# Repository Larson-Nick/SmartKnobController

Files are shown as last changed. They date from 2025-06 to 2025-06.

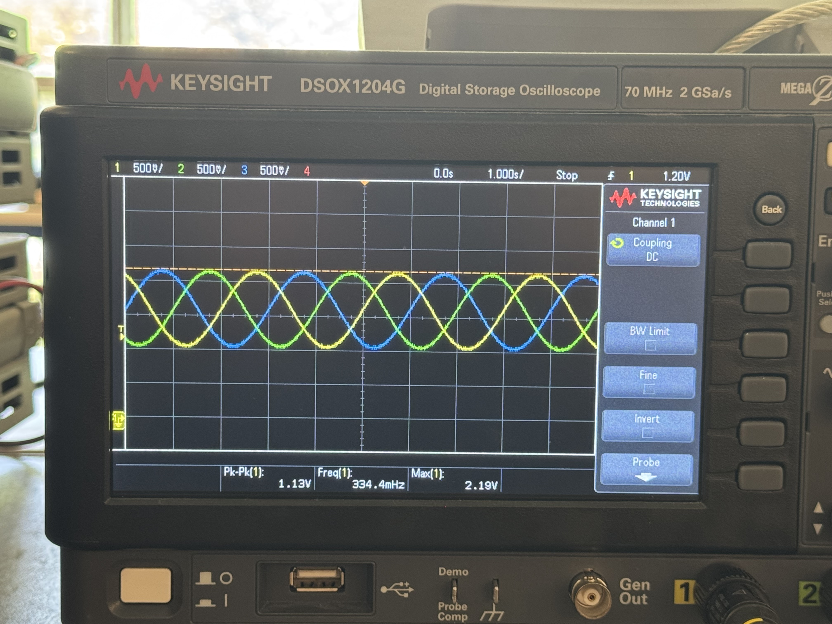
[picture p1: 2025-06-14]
Hardware/MEDIA/SinusoidalCommutation.jpg

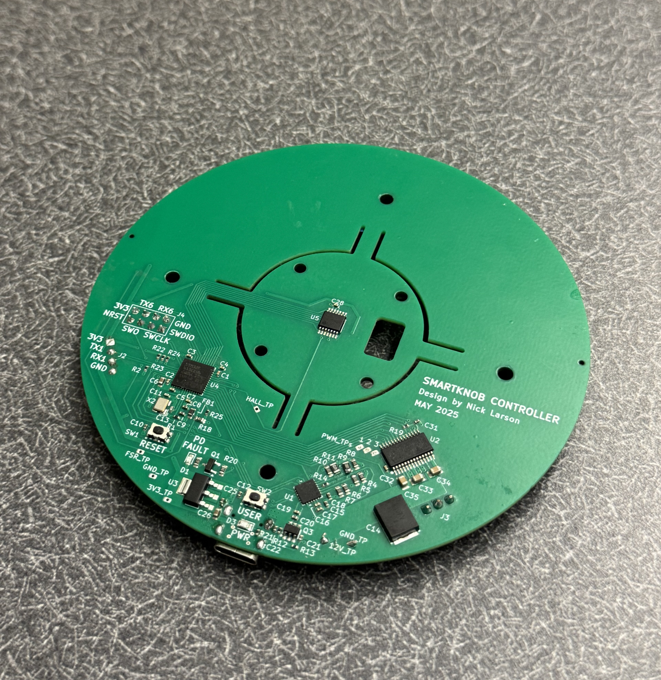
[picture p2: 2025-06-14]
Hardware/MEDIA/PCB.jpg

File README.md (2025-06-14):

# Smart Knob Controller

The Smart Knob Controller is an exploration of how brushless DC motors can breathe new life into one of the most ubiquitous input devices—the humble knob—by enabling dynamic, software-configurable feedback. The result is a clean, tactile, dual-degree-of-freedom controller that feels like multiple knobs in one: snappy detents, elastic spring force, or a completely free-spinning dial. The only limit is your creativity.

📘 [View the full Doxygen documentation here](https://larson-nick.github.io/SmartKnobController)

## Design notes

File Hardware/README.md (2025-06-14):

# Hardware

This folder contains all mechanical and electrical design files for the Smart Knob Controller, created using KiCAD v9.0 and SolidWorks 2024.

## Contents

- **Schematics (.sch)** – Complete circuit design
- **PCB Layout (.kicad_pcb)** – Board layout with mounting features
- **CAD** – For mechanical reference and rendering
- **DATASHEETS** - Incomplete list of datasheet PDFs for components
- **LIBRARIES** – Custom components and footprints
- **MANUFACTURING** - All manufacturing files used for production on JLCPCB.com
- **MEDIA** - Images and videos used for the webpage

Open the `.kicad_pro` or `.pro` file in KiCAD 7.0+ to explore the full project.

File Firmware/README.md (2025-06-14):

# Firmware

This folder contains the full STM32CubeIDE project for the STM32F411 microcontroller used in the Smart Knob Controller.

## Contents

- **Core/** – Source code, header files, and FSM logic
- **Drivers/** – HAL drivers for peripherals and motor control
- **.ioc file** – STM32CubeMX config

Open the project in STM32CubeIDE by double-clicking the `.project` or importing via the `.ioc` file.

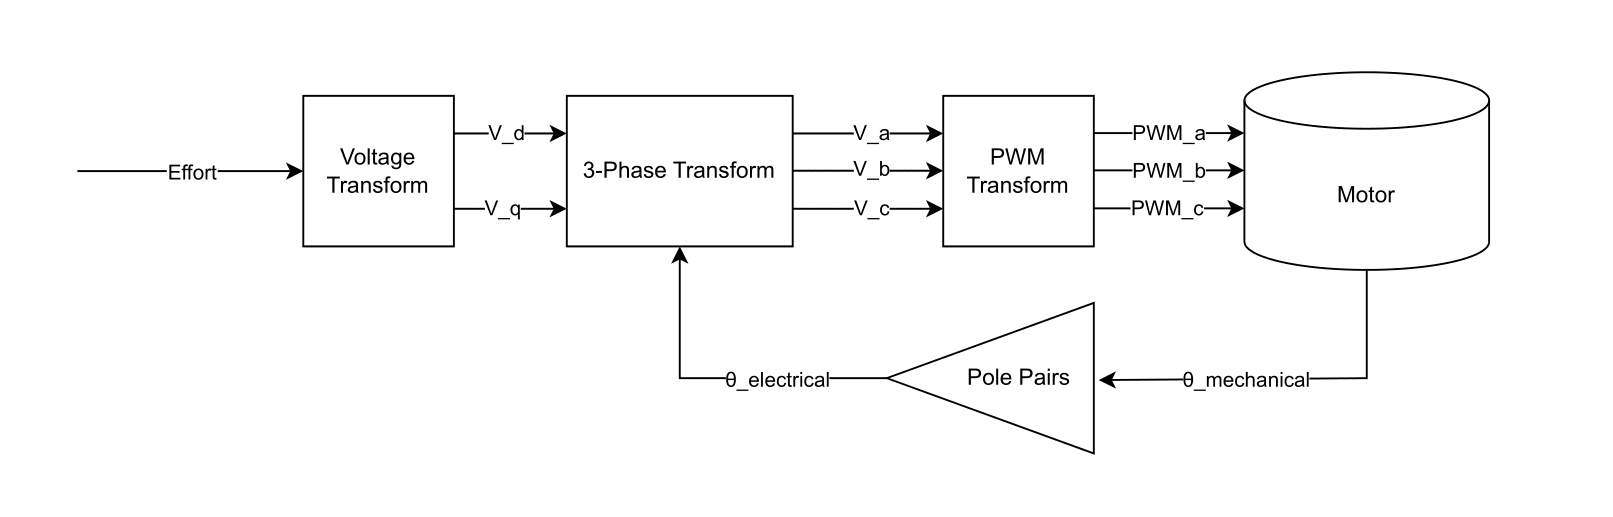
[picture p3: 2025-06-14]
Hardware/MEDIA/CommutationBD.png

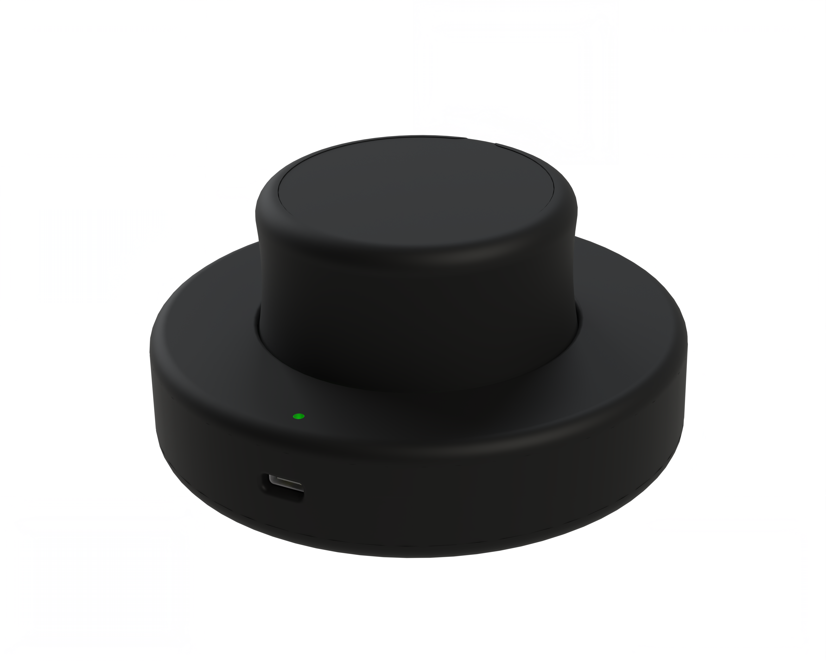
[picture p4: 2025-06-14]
Hardware/MEDIA/Render.png

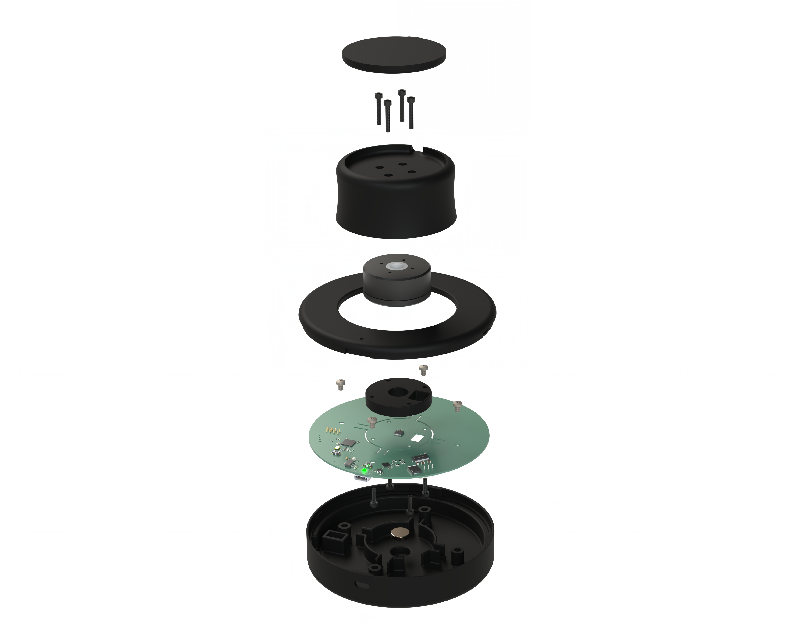
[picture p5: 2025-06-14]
Hardware/MEDIA/ExplodedRender.png

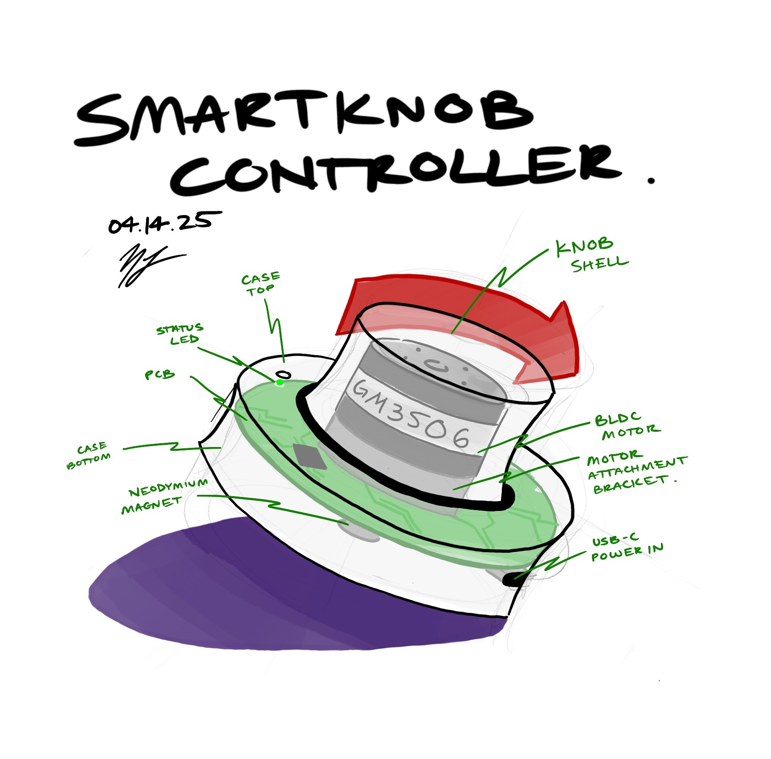
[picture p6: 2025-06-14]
Hardware/MEDIA/SmartKnobSketch.jpg

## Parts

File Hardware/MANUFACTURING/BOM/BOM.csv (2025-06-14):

Reference | Value | Footprint | Description | Qty | LCSC | DNP
Q3 | CJL2623 | 0_TRANSISTOR:SOT-23-6_L2.9-W1.6-P0.95-LS2.8-BR |  | 1 | C139831
U5 | AS5047P-ATSM | 0_SENSOR:TSSOP-14_L5.0-W4.4-P0.65-LS6.4-BL |  | 1 | C962063
D1 | Red | PCM_JLCPCB:D_0603 | -40°C~+85°C Red 0603 LED Indication - Discrete ROHS | 1 | C2286
R20 | 10kΩ | PCM_JLCPCB:R_0603 | 100mW Thick Film Resistors 75V ±100ppm/°C ±1% 10kΩ 0603 Chip Resistor - Surface Mount ROHS | 1 | C25804
R16 | 120Ω | PCM_JLCPCB:R_0603 | 100mW Thick Film Resistors 75V ±100ppm/°C ±1% 120Ω 0603 Chip Resistor - Surface Mount ROHS | 1 | C22787
R18 | 1kΩ | PCM_JLCPCB:R_0603 | 100mW Thick Film Resistors 75V ±100ppm/°C ±1% 1kΩ 0603 Chip Resistor - Surface Mount ROHS | 1 | C21190
R5,R7,R9,R10 | 2.4kΩ | PCM_JLCPCB:R_0603 | 100mW Thick Film Resistors 75V ±100ppm/°C ±1% 2.4kΩ 0603 Chip Resistor - Surface Mount ROHS | 4 | C22940
R4,R6,R8 | 5.1kΩ | PCM_JLCPCB:R_0603 | 100mW Thick Film Resistors 75V ±100ppm/°C ±1% 5.1kΩ 0603 Chip Resistor - Surface Mount ROHS | 3 | C23186
C14 | TCN4107M035R0100E | 0_CAPACITOR:CAP-SMD_L7.3-W6.1_TCN4227M025R0100 | 100uF 35V 100mΩ@100kHz ±20% Tantalum Capacitors ROHS | 1 | C2158793
C24,C33,C34,C35 | 100nF | PCM_JLCPCB:C_0805 | 100V 100nF X7R ±10% 0805 Multilayer Ceramic Capacitors MLCC - SMD/SMT ROHS | 4 | C28233
X2 | X322516MLB4SI | PCM_JLCPCB:OSC-SMD_4P-L3.2-W2.5-BL | 16MHz Surface Mount Crystal 9pF ±10ppm ±20ppm SMD3225-4P Crystals ROHS | 1 | C13738
C2,C3,C4,C5,C16,C17,C19,C28 | 100nF | PCM_JLCPCB:C_0402 | 16V 100nF X7R ±10% 0402 Multilayer Ceramic Capacitors MLCC - SMD/SMT ROHS | 8 | C1525
C26 | 2.2uF | PCM_JLCPCB:C_0603 | 16V 2.2uF X5R ±10% 0603 Multilayer Ceramic Capacitors MLCC - SMD/SMT ROHS | 1 | C23630
C6 | 4.7uF | PCM_JLCPCB:C_0603 | 16V 4.7uF X5R ±10% 0603 Multilayer Ceramic Capacitors MLCC - SMD/SMT ROHS | 1 | C19666
U3 | TLV76133DCYR | 0_PWR:SOT-223-4_L6.5-W3.5-P2.30-LS7.0-TR | 1A Fixed 3.3V Positive electrode 16V SOT-223 Voltage Regulators - Linear, Low Drop Out (LDO) Regulators ROHS | 1 | C7527500
C8,C9,C10,C12,C15,C18,C20,C21,C22,C25,C31 | 1uF | PCM_JLCPCB:C_0402 | 25V 1uF X5R ±10% 0402 Multilayer Ceramic Capacitors MLCC - SMD/SMT ROHS | 11 | C52923
J1 | Connector, USB-TYPE-C-16P | PCM_JLCPCB:TYPE-C-SMD_HX-TYPE-C-16PIN | 3A 1 Horizontal attachment 16P Female -25℃~+85℃ Type-C SMD USB Connectors ROHS | 1 | C2927039
FB1 | 120R | PCM_JLCPCB:FB_0603 | 450mΩ ±25% 600Ω@100MHz 0603 Ferrite Beads ROHS | 1 | C1002
C7,C32 | 10nF | PCM_JLCPCB:C_0402 | 50V 10nF X7R ±10% 0402 Multilayer Ceramic Capacitors MLCC - SMD/SMT ROHS | 2 | C15195
C11,C13 | 10pF | PCM_JLCPCB:C_0402 | 50V 10pF C0G ±5% 0402 Multilayer Ceramic Capacitors MLCC - SMD/SMT ROHS | 2 | C32949
C1 | 4.7nF | PCM_JLCPCB:C_0402 | 50V 4.7nF X7R ±10% 0402 Multilayer Ceramic Capacitors MLCC - SMD/SMT ROHS | 1 | C1538
C23 | 4.7nF | PCM_JLCPCB:C_0805 | 50V 4.7nF X7R ±10% 0805 Multilayer Ceramic Capacitors MLCC - SMD/SMT ROHS | 1 | C1744
Q1 | 2N7002 | PCM_JLCPCB:Q_SOT-23 | 60V 115mA 200mW 7.5Ω@10V,500mA 2.5V@250uA 1 N-Channel SOT-23 MOSFETs ROHS | 1 | C8545
R21 | 47Ω | PCM_JLCPCB:R_0402 | 62.5mW Thick Film Resistors 50V ±1% ±200ppm/°C 47Ω 0402 Chip Resistor - Surface Mount ROHS | 1 | C25118
R1,R2,R12,R19,R25 | 10kΩ | PCM_JLCPCB:R_0402 | 62.5mW Thick Film Resistors 50V ±100ppm/°C ±1% 10kΩ 0402 Chip Resistor - Surface Mount ROHS | 5 | C25744
R13,R14 | 1kΩ | PCM_JLCPCB:R_0402 | 62.5mW Thick Film Resistors 50V ±100ppm/°C ±1% 1kΩ 0402 Chip Resistor - Surface Mount ROHS | 2 | C11702
R22,R23,R24 | 2.4kΩ | PCM_JLCPCB:R_0402 | 62.5mW Thick Film Resistors 50V ±100ppm/°C ±1% 2.4kΩ 0402 Chip Resistor - Surface Mount ROHS | 3 | C25882
U4 | STM32F411CEU6 | 0_MCU:STM32F411CEU6 | ARM-M4 100MHz UFQFPN-48(7x7) Microcontrollers (MCU/MPU/SOC) ROHS | 1 | C60420
D3 | Green | PCM_JLCPCB:D_0805 | Emerald 0805 LED Indication - Discrete ROHS | 1 | C2297
U2 | DRV8313PWPR | 0_DRIVER:HTSSOP-28_L9.8-W4.5-P0.65-LS6.6-BL-EP | HTSSOP-28-EP-4.5mm Brushless DC (BLDC) Motor Driver ROHS | 1 | C92482
SW1,SW2 | KMR223GLFG | 0_MISC:SW-SMD_5P-L4.2-W2.8-P1.60-LS4.6-TR | Round Button 10mA Standing paste SPST - normally open 32V 200gf SMD Tactile Switches ROHS | 2 | C221678
U6 | A1304ELHLX-T | 0_SENSOR:SOT-23-3_L3.0-W1.9-P0.95-LS2.9-BL | SOT-23W Linear Hall Sensors ROHS | 1 | C545185
U1 | CYPD3177-24LQXQT | 0_PWR:QFN24_CYPD3177-24LQXQT_INF | Stand-alone USB PD controller (with sink Auto-run mode), QFN-24 | 1 | C5904158

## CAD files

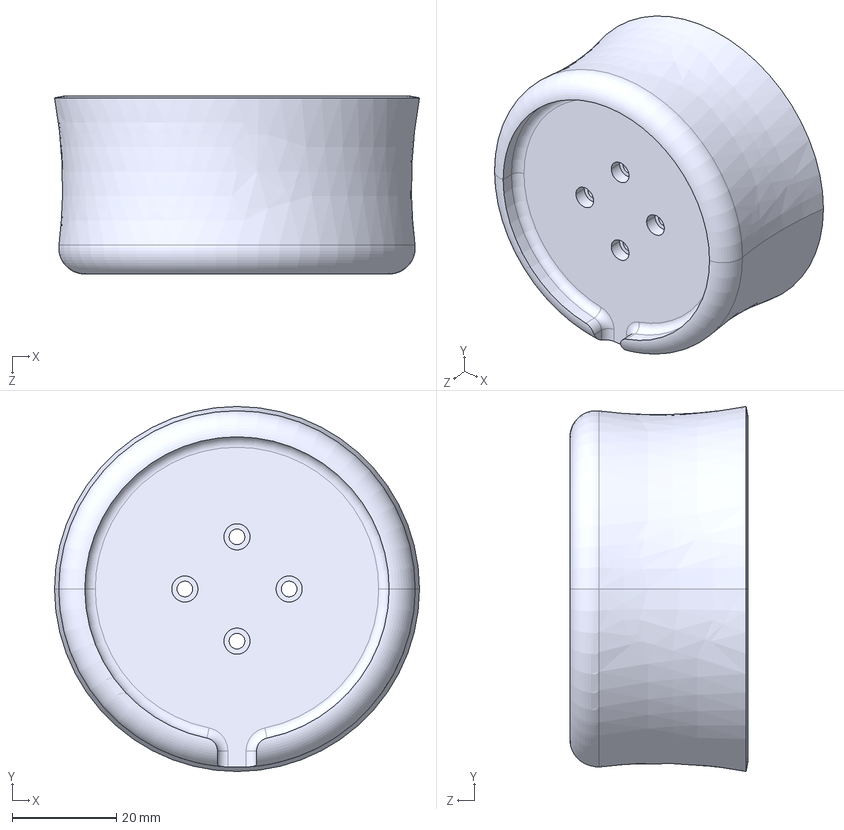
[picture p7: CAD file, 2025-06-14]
Hardware/CAD/REV3_PrintFiles/Knob_REV3.STEP
70.0 x 70.0 x 34.2 mm

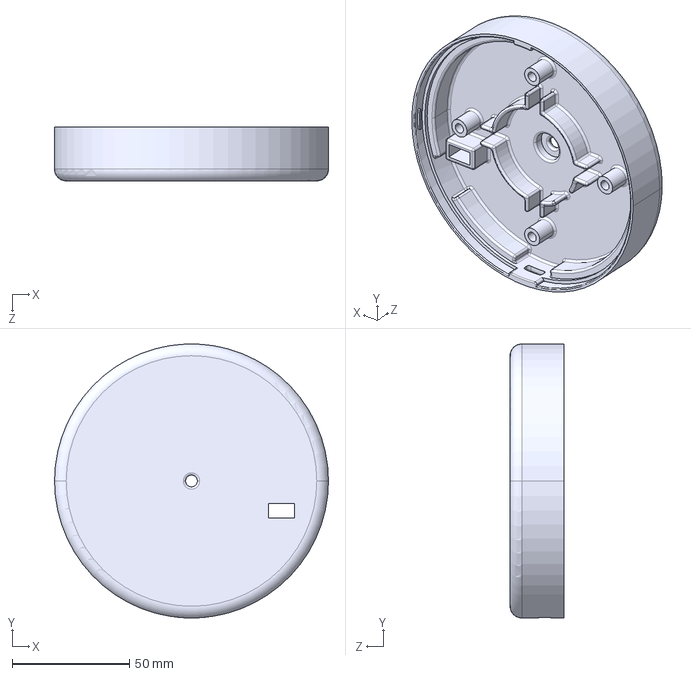
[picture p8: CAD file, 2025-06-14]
Hardware/CAD/REV3_PrintFiles/Base_REV3.STEP
117.0 x 117.0 x 23.0 mm

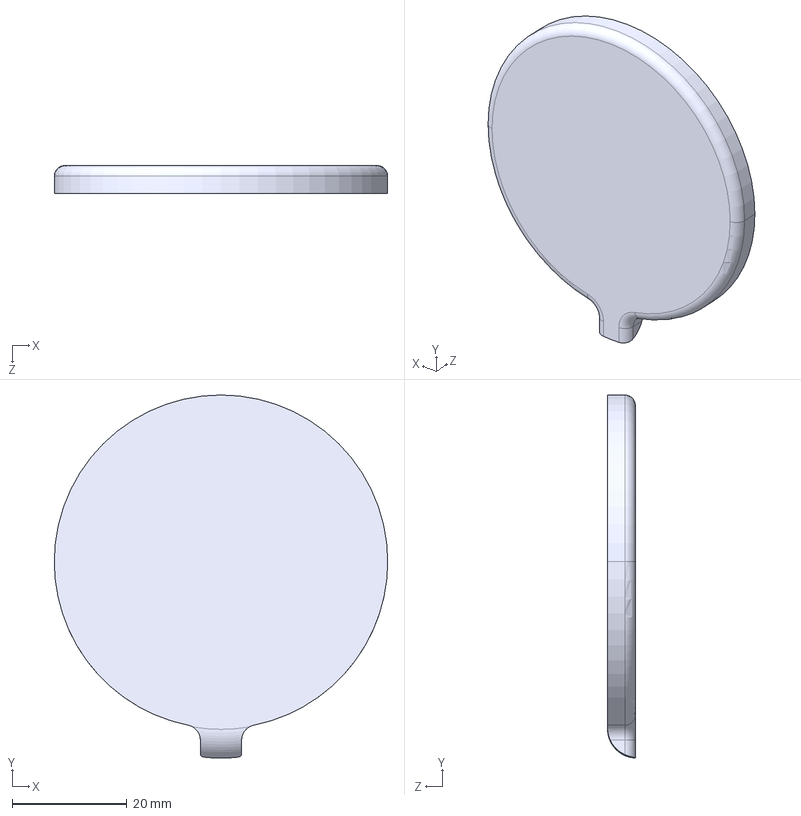
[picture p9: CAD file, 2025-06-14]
Hardware/CAD/REV3_PrintFiles/Cap_REV3.STEP
58.1 x 63.2 x 4.85 mm

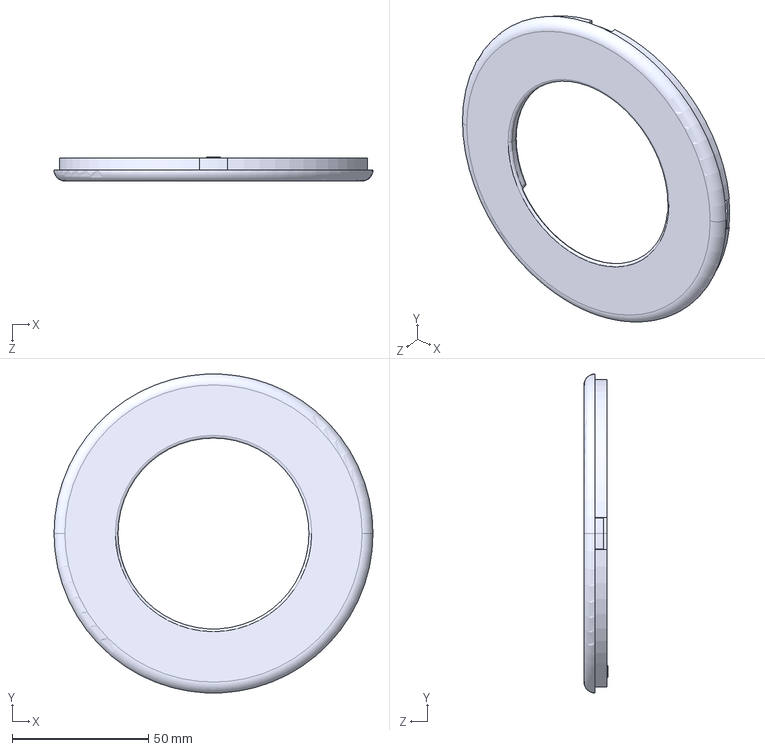
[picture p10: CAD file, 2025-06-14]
Hardware/CAD/REV3_PrintFiles/Top_REV3.STEP
117.0 x 116.9 x 8.84 mm

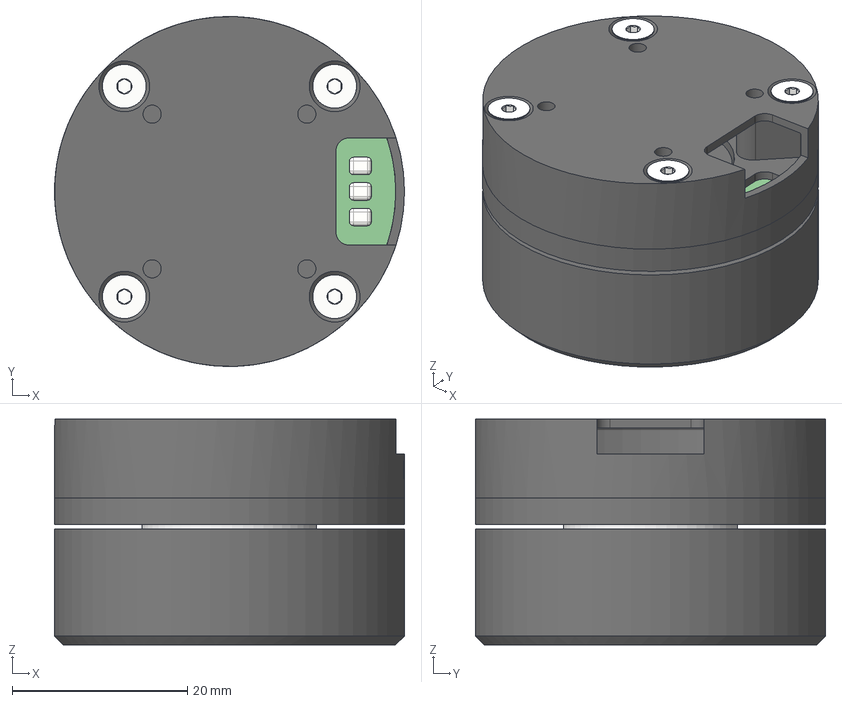
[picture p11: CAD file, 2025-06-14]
Hardware/CAD/GM3506 With Encoder.step
40.0 x 40.0 x 25.8 mm
По умолчанию
По умолчанию_ 1
Magnet
Encoder
93395A179_316 Stainless Steel Hex Drive Flat Head Screw x 4

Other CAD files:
Hardware/CAD/HTSSOP-28_L9.7-W4.4-H1.2-LS6.4-P0.65_1.step.SLDPRT
Hardware/CAD/SW-SMD_5P-L4.2-W2.8-P1.60-LS4.6-TR_1.step.SLDPRT
Hardware/CAD/Part60.SLDPRT
Hardware/CAD/D_0603_1.step.SLDPRT
Hardware/CAD/TSSOP-14_L5.0-W4.4-H1.0-LS6.4-P0.65_1.step.SLDPRT
Hardware/CAD/PinHeader_2x04_P2.54mm_Vertical_1.step.SLDPRT
Hardware/CAD/D_0805_1.step.SLDPRT
Hardware/CAD/STM32F411CEU6_1.step.SLDPRT
Hardware/CAD/R_0402_1.step.SLDPRT
Hardware/CAD/SmartKnobController_ME507_PCB_1.step.SLDPRT
Hardware/CAD/SOT-23-6_L2.9-W1.6-H1.5-LS2.8-P0.95_1.step.SLDPRT
Hardware/CAD/Part59.SLDPRT
Hardware/CAD/C_0402_1.step.SLDPRT
Hardware/CAD/CAP-SMD_L7.3-W6.1_TCN4227M025R0100_1.step.SLDPRT
Hardware/CAD/C_0603_1.step.SLDPRT
Hardware/CAD/C_0805_1.step.SLDPRT
Hardware/CAD/Cap.SLDPRT
Hardware/CAD/FB_0603_1.step.SLDPRT
Hardware/CAD/JST_XH_S3B-XH-A_1x03_P2.50mm_Horizontal_1.step.SLDPRT
Hardware/CAD/Knob.SLDPRT
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

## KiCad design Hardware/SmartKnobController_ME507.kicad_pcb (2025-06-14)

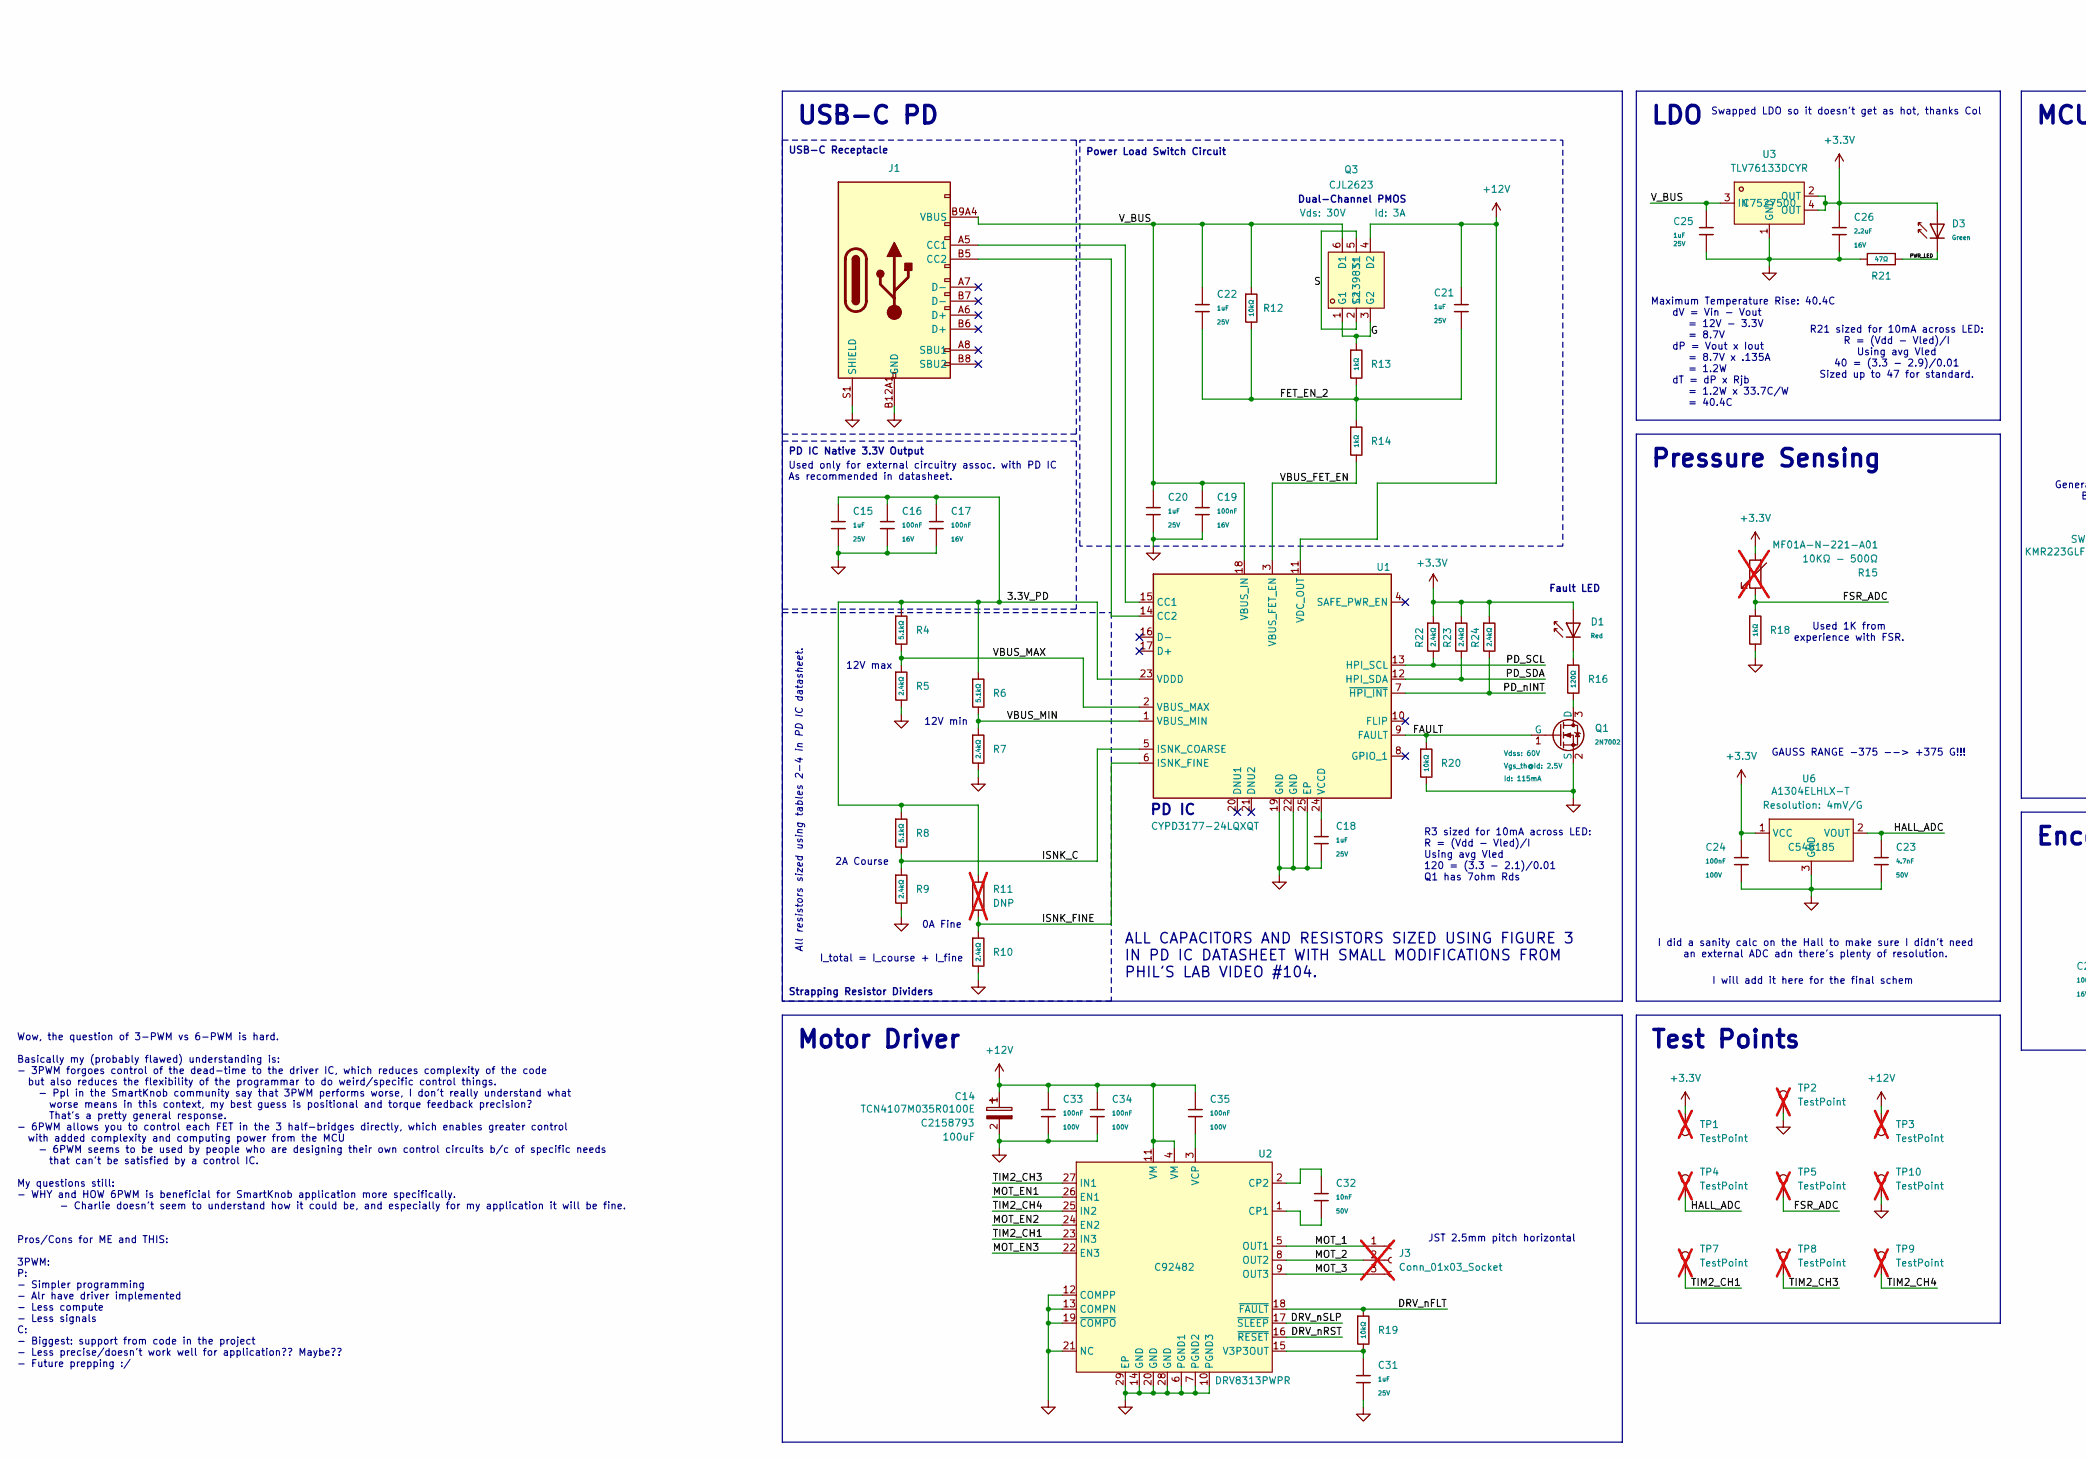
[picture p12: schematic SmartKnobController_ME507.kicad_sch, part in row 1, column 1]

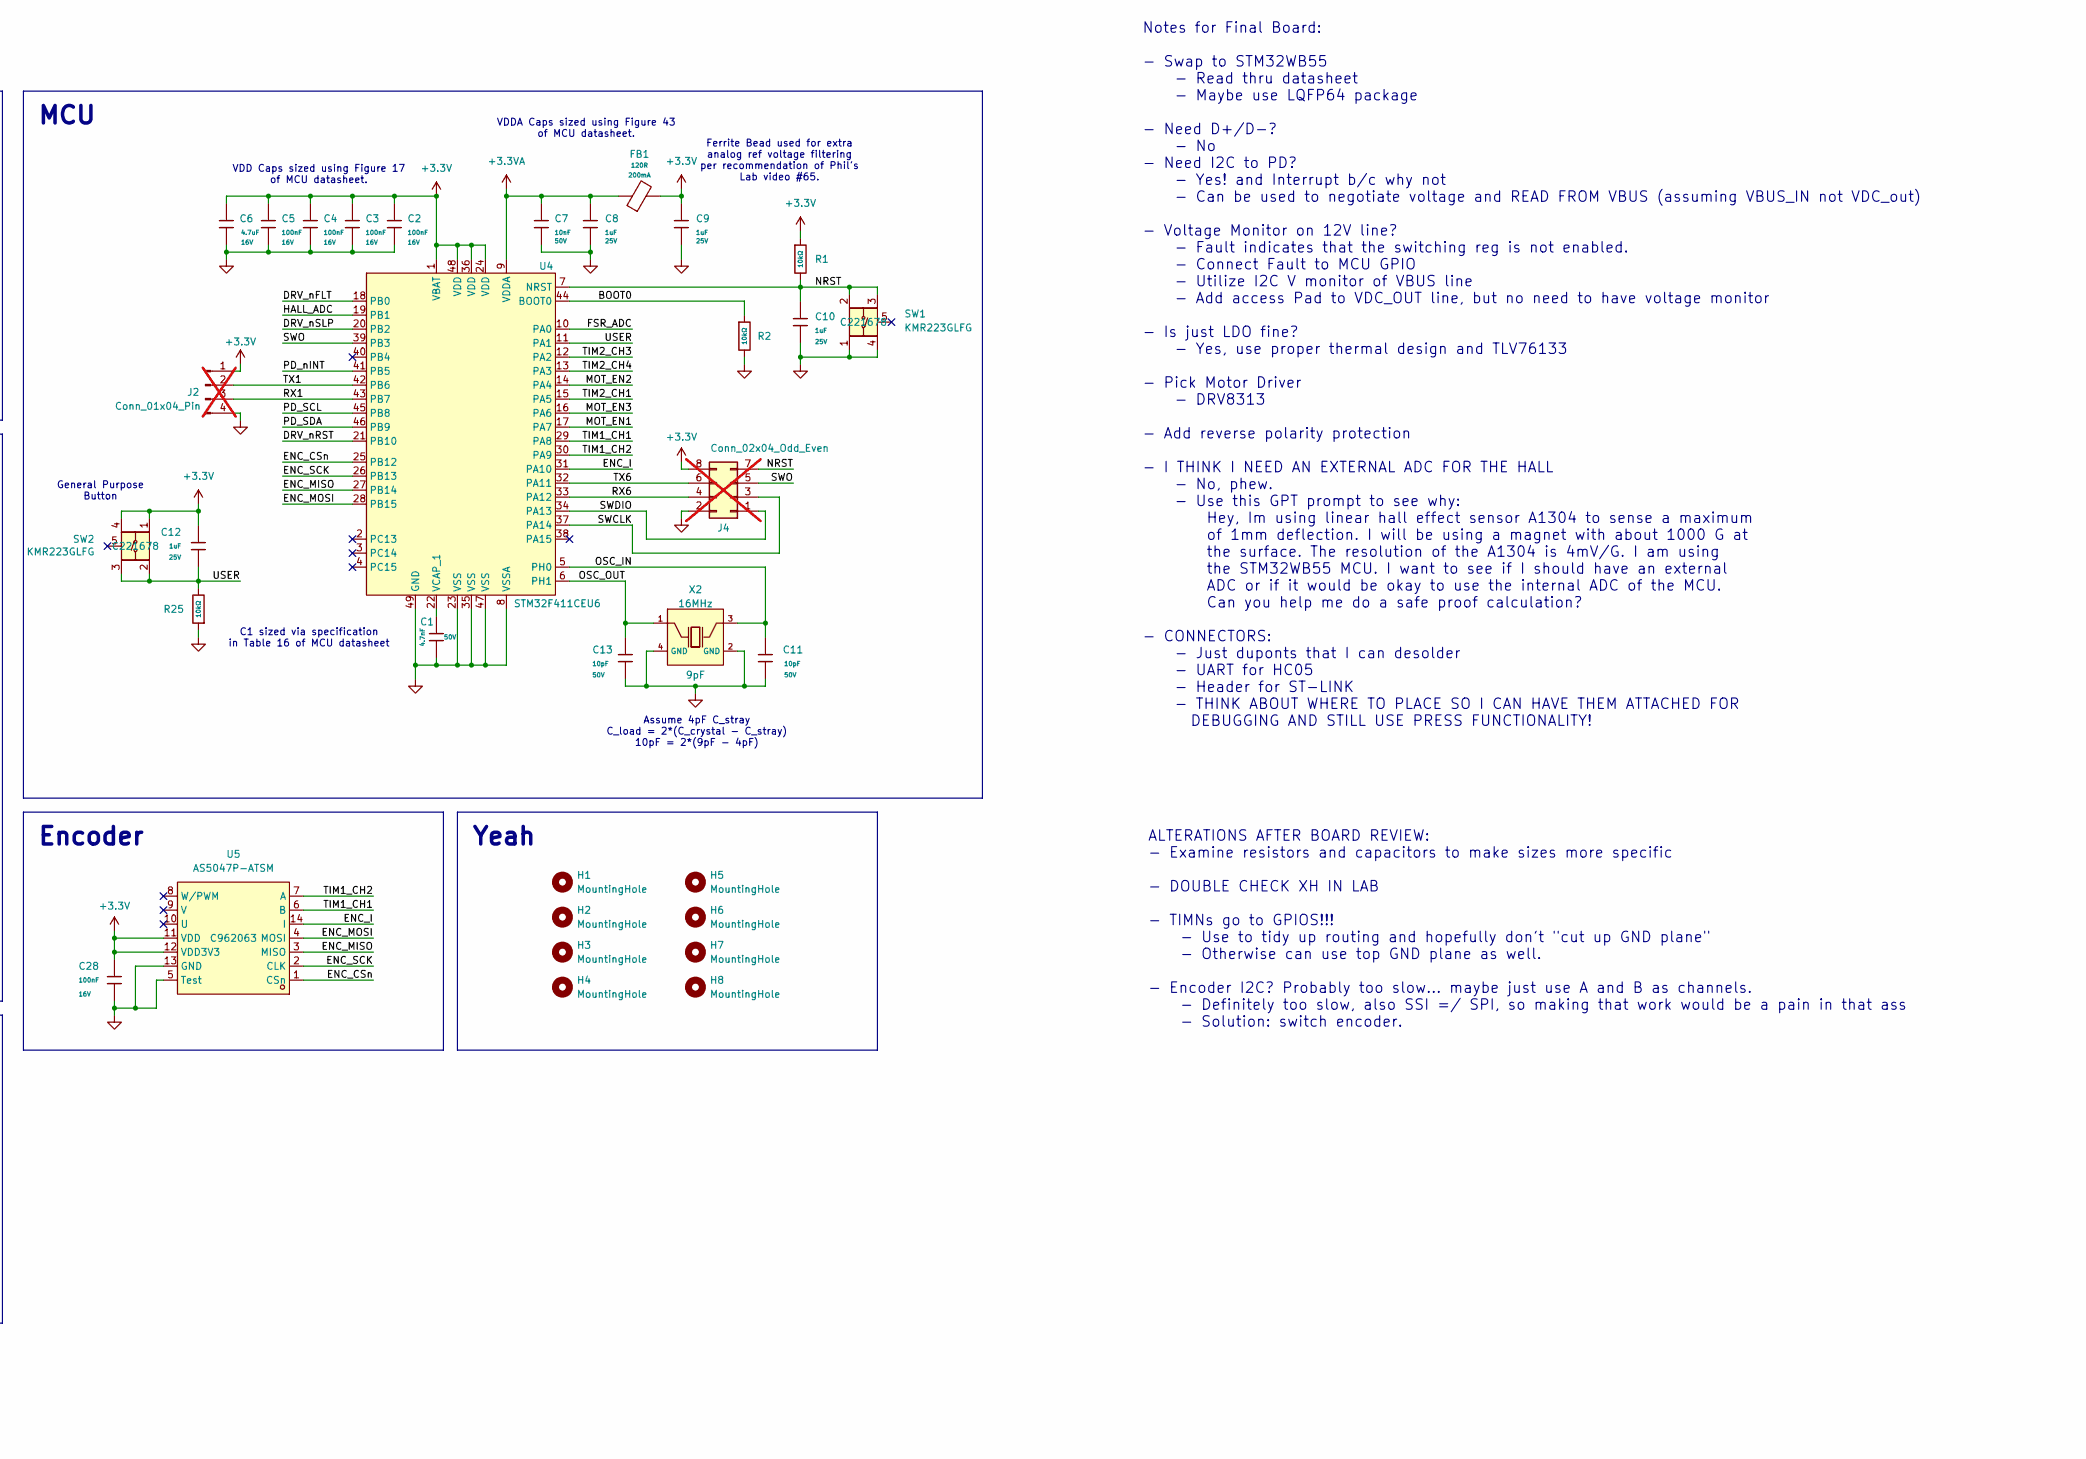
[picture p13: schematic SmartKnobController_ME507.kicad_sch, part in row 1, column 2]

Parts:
C1: 4.7nF; C_0402; Voltage Rated 50V; Tolerance ±10%; Part 0402B472K500NT; LCSC C1538
C2, C3, C4, C5, C16, C17, C19, C28: 100nF; C_0402; Voltage Rated 16V; Tolerance ±10%; Part CL05B104KO5NNNC; LCSC C1525
C6: 4.7uF; C_0603; Voltage Rated 16V; Tolerance ±10%; Part CL10A475KO8NNNC; LCSC C19666
C7, C32: 10nF; C_0402; Voltage Rated 50V; Tolerance ±10%; Part CL05B103KB5NNNC; LCSC C15195
C8, C9, C10, C12, C15, C18, C20, C21, C22, C25, C31: 1uF; C_0402; Voltage Rated 25V; Tolerance ±10%; Part CL05A105KA5NQNC; LCSC C52923
C11, C13: 10pF; C_0402; Voltage Rated 50V; Tolerance ±5%; Part CL05C100JB5NNNC; LCSC C32949
C14: TCN4107M035R0100E; CAP-SMD_L7.3-W6.1_TCN4227M025R0100; LCSC Part C2158793
C23: 4.7nF; C_0805; Voltage Rated 50V; Tolerance ±10%; Part 0805B472K500NT; LCSC C1744
C24, C33, C34, C35: 100nF; C_0805; Voltage Rated 100V; Tolerance ±10%; Part CL21B104KCFNNNE; LCSC C28233
C26: 2.2uF; C_0603; Voltage Rated 16V; Tolerance ±10%; Part CL10A225KO8NNNC; LCSC C23630
D1: Red; D_0603; Part KT-0603R; LCSC C2286
D3: Green; D_0805; Part KT-0805G; LCSC C2297
FB1: 120R; FB_0603; Current Rating 200mA; Tolerance ±25%; Part GZ1608D601TF; LCSC C1002
H1, H2, H3, H4: MountingHole; MountingHole_2.7mm_M2.5
H5, H6, H7, H8: MountingHole; MountingHole_3.2mm_M3
J1: Connector, USB-TYPE-C-16P; TYPE-C-SMD_HX-TYPE-C-16PIN; LCSC C2927039
J2: Conn_01x04_Pin; PinHeader_1x04_P2.54mm_Horizontal; not fitted
J3: Conn_01x03_Socket; JST_XH_S3B-XH-A_1x03_P2.50mm_Horizontal; not fitted
J4: Conn_02x04_Odd_Even; PinHeader_2x04_P2.54mm_Vertical; not fitted
Q1: 2N7002; Q_SOT-23; Part 2N7002; LCSC C8545
Q3: CJL2623; SOT-23-6_L2.9-W1.6-P0.95-LS2.8-BR; LCSC Part C139831
R1, R2, R12, R19, R25: 10kΩ; R_0402; Overload Voltage (Max) 50V; Tolerance ±1%; Part 0402WGF1002TCE; LCSC C25744
R4, R6, R8: 5.1kΩ; R_0603; Overload Voltage (Max) 75V; Tolerance ±1%; Part 0603WAF5101T5E; LCSC C23186
R5, R7, R9, R10: 2.4kΩ; R_0603; Overload Voltage (Max) 75V; Tolerance ±1%; Part 0603WAF2401T5E; LCSC C22940
R11: DNP; R_0603; not fitted
R13, R14: 1kΩ; R_0402; Overload Voltage (Max) 50V; Tolerance ±1%; Part 0402WGF1001TCE; LCSC C11702
R15: 10KΩ - 500Ω; MF01A-N-221-A05; not fitted
R16: 120Ω; R_0603; Overload Voltage (Max) 75V; Tolerance ±1%; Part 0603WAF1200T5E; LCSC C22787
R18: 1kΩ; R_0603; Overload Voltage (Max) 75V; Tolerance ±1%; Part 0603WAF1001T5E; LCSC C21190
R20: 10kΩ; R_0603; Overload Voltage (Max) 75V; Tolerance ±1%; Part 0603WAF1002T5E; LCSC C25804
R21: 47Ω; R_0402; Overload Voltage (Max) 50V; Tolerance ±1%; Part 0402WGF470JTCE; LCSC C25118
R22, R23, R24: 2.4kΩ; R_0402; Overload Voltage (Max) 50V; Tolerance ±1%; Part 0402WGF2401TCE; LCSC C25882
SW1, SW2: KMR223GLFG; SW-SMD_5P-L4.2-W2.8-P1.60-LS4.6-TR; LCSC Part C221678
TP1, TP2, TP3, TP4, TP5, TP7, TP8, TP9, TP10: TestPoint; Test Point; not fitted
U1: CYPD3177-24LQXQT; QFN24_CYPD3177-24LQXQT_INF; LCSC C5904158
U2: DRV8313PWPR; HTSSOP-28_L9.8-W4.5-P0.65-LS6.6-BL-EP; LCSC Part C92482
U3: TLV76133DCYR; SOT-223-4_L6.5-W3.5-P2.30-LS7.0-TR; LCSC Part C7527500
U4: STM32F411CEU6; LCSC C60420
U5: AS5047P-ATSM; TSSOP-14_L5.0-W4.4-P0.65-LS6.4-BL; LCSC Part C962063
U6: A1304ELHLX-T; SOT-23-3_L3.0-W1.9-P0.95-LS2.9-BL; LCSC Part C545185
X2: X322516MLB4SI; OSC-SMD_4P-L3.2-W2.5-BL; Frequency Tolerance ±10ppm; Part X322516MLB4SI; LCSC C13738

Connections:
+3.3V: C2.1, C3.1, C4.1, C5.1, C6.1, C9.1, C12.2, C24.1, C26.1, C28.2, D1.2, D3.2, FB1.2, J2.1, J4.8, R1.1, R15.2, R22.1, R23.1, R24.1, SW2.1, SW2.4, TP1.1, U3.2 (OUT), U3.4 (OUT), U4.1 (VBAT), U4.24 (VDD), U4.36 (VDD), U4.48 (VDD), U5.11 (VDD), U5.12 (VDD3V3), U6.1 (VCC)
+3.3VA: C7.1, C8.1, FB1.1, U4.9 (VDDA)
+12V: C14.1, C21.1, C33.1, C34.1, C35.1, Q3.4 (D2), TP3.1, U1.11 (VDC_OUT), U2.4 (VM), U2.11 (VM)
/3.3V_PD: C15.1, C16.1, C17.1, R4.1, R6.1, R8.1, R11.1, U1.23 (VDDD)
/BOOT0: R2.1, U4.44 (BOOT0)
/DRV_nFLT: R19.1, U2.18 (~FAULT), U4.18 (PB0)
/DRV_nRST: U2.16 (~RESET), U4.21 (PB10)
/DRV_nSLP: U2.17 (~SLEEP), U4.20 (PB2)
/ENC_CSn: U4.25 (PB12), U5.1 (CSn)
/ENC_I: U4.31 (PA10), U5.14 (I)
/ENC_MISO: U4.27 (PB14), U5.3 (MISO)
/ENC_MOSI: U4.28 (PB15), U5.4 (MOSI)
/ENC_SCK: U4.26 (PB13), U5.2 (CLK)
/FAULT: Q1.1 (G), R20.1, U1.9 (FAULT)
/FET_EN_2: C21.2, C22.2, R12.2, R13.2, R14.1
/FSR_ADC: R15.1, R18.1, TP5.1, U4.10 (PA0)
/G: Q3.1 (G1), Q3.3 (G2), R13.1
/HALL_ADC: C23.1, TP4.1, U4.19 (PB1), U6.2 (VOUT)
/ISNK_C: R8.2, R9.1, U1.5 (ISNK_COARSE)
/ISNK_FINE: R10.1, R11.2, U1.6 (ISNK_FINE)
/MOT_1: J3.1, U2.5 (OUT1)
/MOT_2: J3.2, U2.8 (OUT2)
/MOT_3: J3.3, U2.9 (OUT3)
/MOT_EN1: U2.26 (EN1), U4.17 (PA7)
/MOT_EN2: U2.24 (EN2), U4.14 (PA4)
/MOT_EN3: U2.22 (EN3), U4.16 (PA6)
/NRST: C10.1, J4.7, R1.2, SW1.2, SW1.3, U4.7 (NRST)
/OSC_IN: C11.1, U4.5 (PH0), X2.3 (OSC)
/OSC_OUT: C13.1, U4.6 (PH1), X2.1 (OSC)
/PD_SCL: R22.2, U1.13 (HPI_SCL), U4.45 (PB8)
/PD_SDA: R23.2, U1.12 (HPI_SDA), U4.46 (PB9)
/PD_nINT: R24.2, U1.7 (~HPI_INT), U4.41 (PB5)
/PWR_LED: D3.1, R21.2
/RX1: J2.3, U4.43 (PB7)
/RX6: J4.4, U4.33 (PA12)
/S: Q3.2 (S2), Q3.5 (S1)
/SWCLK: J4.3, U4.37 (PA14)
/SWDIO: J4.1, U4.34 (PA13)
/SWO: J4.5, U4.39 (PB3)
/TIM1_CH1: U4.29 (PA8), U5.6 (B)
/TIM1_CH2: U4.30 (PA9), U5.7 (A)
/TIM2_CH1: TP7.1, U2.23 (IN3), U4.15 (PA5)
/TIM2_CH3: TP8.1, U2.27 (IN1), U4.12 (PA2)
/TIM2_CH4: TP9.1, U2.25 (IN2), U4.13 (PA3)
/TX1: J2.2, U4.42 (PB6)
/TX6: J4.6, U4.32 (PA11)
/USER: C12.1, R25.2, SW2.2, SW2.3, U4.11 (PA1)
/VBUS_FET_EN: R14.2, U1.3 (VBUS_FET_EN)
/VBUS_MAX: R4.2, R5.1, U1.2 (VBUS_MAX)
/VBUS_MIN: R6.2, R7.1, U1.1 (VBUS_MIN)
/V_BUS: C19.1, C20.1, C22.1, C25.1, J1.A9B4 (VBUS), J1.B9A4 (VBUS), Q3.6 (D1), R12.1, U1.18 (VBUS_IN), U3.3 (IN)
GND: C1.2, C2.2, C3.2, C4.2, C5.2, C6.2, C7.2, C8.2, C9.2, C10.2, C11.2, C13.2, C14.2, C15.2, C16.2, C17.2, C18.2, C19.2, C20.2, C23.2, C24.2, C25.2, C26.2, C28.1, C31.2, C33.2, C34.2, J1.A12B1 (GND), J1.B12A1 (GND), J1.S1 (SHIELD), J2.4, J4.2, Q1.2 (S), R2.2, R5.2, R7.2, R9.2, R10.2, R18.2, R20.2, R21.1, R25.1, SW1.1, SW1.4, TP2.1, TP10.1, U1.19 (GND), U1.22 (GND), U1.25 (EP), U2.6 (PGND1), U2.7 (PGND2), U2.10 (PGND3), U2.12 (COMPP), U2.13 (COMPN), U2.14 (GND), U2.19 (~COMPO), U2.20 (GND), U2.21 (NC), U2.28 (GND), U2.29 (EP), U3.1 (GND), U4.8 (VSSA), U4.23 (VSS), U4.35 (VSS), U4.47 (VSS), U4.49 (GND), U5.5 (Test), U5.13 (GND), U6.3 (GND), X2.2 (GND), X2.4 (GND)
unnamed: D1.1, R16.1
unnamed: J1.A5 (CC1), U1.15 (CC1)
unnamed: J1.B5 (CC2), U1.14 (CC2)
unnamed: Q1.3 (D), R16.2
unnamed: C18.1, U1.24 (VCCD)
unnamed: C32.2, U2.1 (CP1)
unnamed: C32.1, U2.2 (CP2)
unnamed: C31.1, R19.2, U2.15 (V3P3OUT)
unnamed: C35.2, U2.3 (VCP)
unnamed: C1.1, U4.22 (VCAP_1)

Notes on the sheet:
Dual-Channel PMOS
R3 sized for 10mA across LED: R = (Vdd - Vled)/I Using avg Vled 120 = (3.3 - 2.1)/0.01 Q1 has 7ohm Rds
Used only for external circuitry assoc. with PD IC As recommended in datasheet.
Used 1K from experience with FSR.
Fault LED
Maximum Temperature Rise: 40.4C dV = Vin - Vout = 12V - 3.3V = 8.7V dP = Vout x Iout = 8.7V x .135A = 1.2W dT = dP x Rjb = 1.2W x 33.7C/W = 40.4C
VDDA Caps sized using Figure 43 of MCU datasheet.
R21 sized for 10mA across LED: R = (Vdd - Vled)/I Using avg Vled 40 = (3.3 - 2.9)/0.01 Sized up to 47 for standard.
12V min
2A Course
C1 sized via specification in Table 16 of MCU datasheet
GAUSS RANGE -375 --> +375 G!!!
0A Fine
ALTERATIONS AFTER BOARD REVIEW: - Examine resistors and capacitors to make sizes more specific - DOUBLE CHECK XH IN LAB - TIMNs go to GPIOS!!! - Use to tidy up routing and hopefully don't "cut up GND plane" - Otherwise can use top GND plane as well. - Encoder I2C? Probably too slow... maybe just us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
PD IC
VDD Caps sized using Figure 17 of MCU datasheet.
Power Load Switch Circuit
General Purpose Button
JST 2.5mm pitch horizontal
I did a sanity calc on the Hall to make sure I didn't need an external ADC adn there's plenty of resolution.
Notes for Final Board: - Swap to STM32WB55 - Read thru datasheet - Maybe use LQFP64 package - Need D+/D-? - No - Need I2C to PD? - Yes! and Interrupt b/c why not - Can be used to negotiate voltage and READ FROM VBUS (assuming VBUS_IN not VDC_out) - Voltage Monitor on 12V line? - Fault indicates tha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
Swapped LDO so it doesn't get as hot, thanks Col
Wow, the question of 3-PWM vs 6-PWM is hard. Basically my (probably flawed) understanding is: - 3PWM forgoes control of the dead-time to the driver IC, which reduces complexity of the code but also reduces the flexibility of the programmar to do weird/specific control things. - Ppl in the SmartKnob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
Assume 4pF C_stray C_load = 2*(C_crystal - C_stray) 10pF = 2*(9pF - 4pF)
I will add it here for the final schem
I_total = I_course + I_fine
12V max
All resistors sized using tables 2-4 in PD IC datasheet.
ALL CAPACITORS AND RESISTORS SIZED USING FIGURE 3 IN PD IC DATASHEET WITH SMALL MODIFICATIONS FROM PHIL'S LAB VIDEO #104.
Ferrite Bead used for extra analog ref voltage filtering per recommendation of Phil's Lab video #65.
Motor Driver
LDO
Pressure Sensing
Encoder
PD IC Native 3.3V Output
Strapping Resistor Dividers
Test Points
Yeah
USB-C Receptacle
USB-C PD

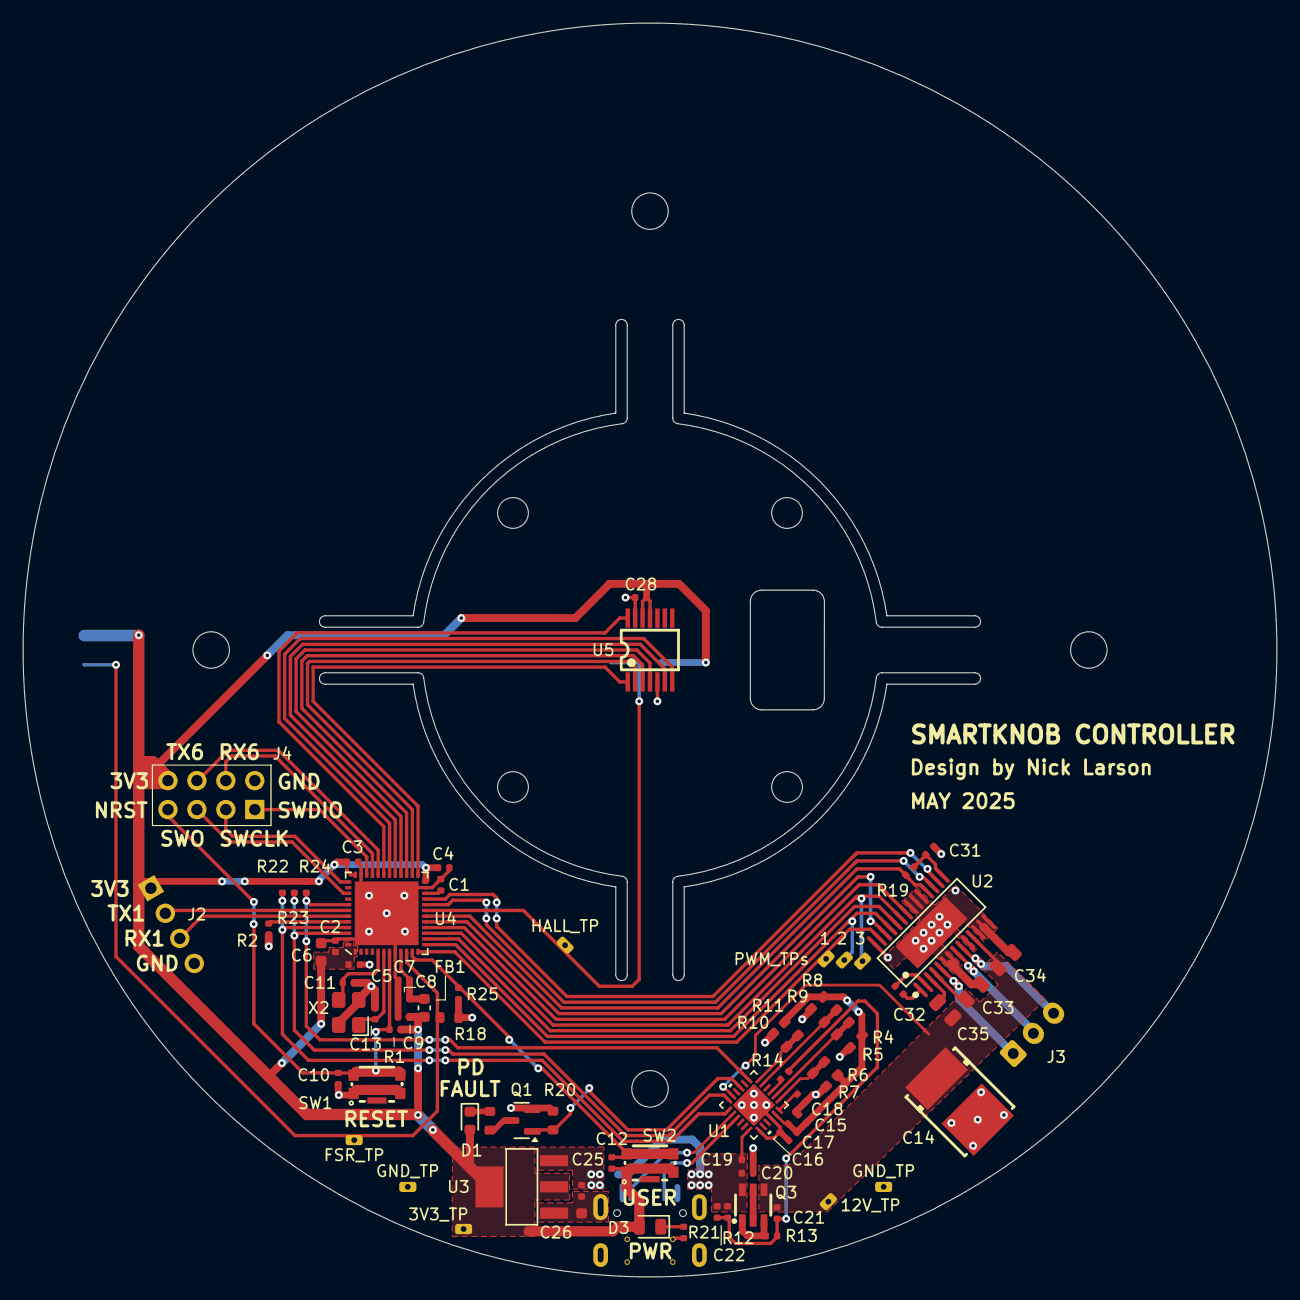
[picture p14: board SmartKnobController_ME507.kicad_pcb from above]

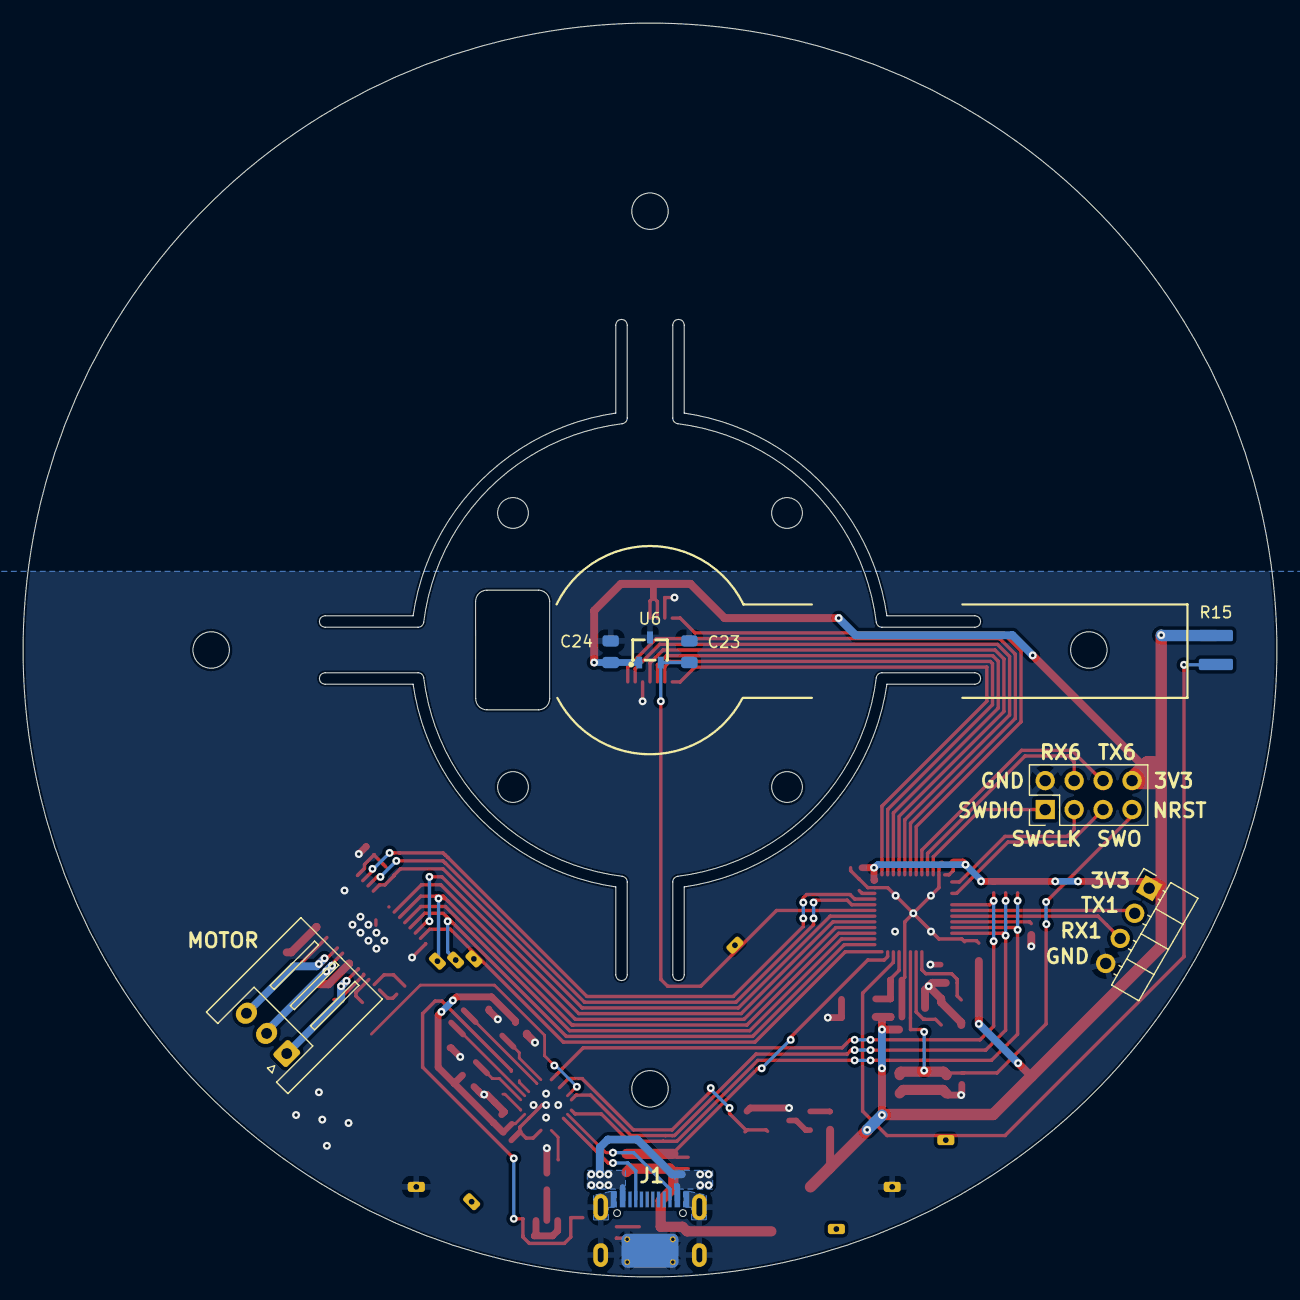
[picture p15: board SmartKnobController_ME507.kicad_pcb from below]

Board: 2 copper layers, 110.0 x 110.0 mm, 90 parts (8 on the bottom side), 62 nets.

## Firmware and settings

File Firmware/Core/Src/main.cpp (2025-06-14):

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
/* Includes ------------------------------------------------------------------*/
#include "main.h"

/* USER CODE BEGIN Includes */
#include "stdio.h"
#include "stdint.h"
#include "string.h"

#include "time_utils.h"

#include "gpio.h"
#include "encoder.h"
#include "motor.h"
#include "PID.h"
#include "FSM.h"
#include "hall.h"
/* USER CODE END Includes */

ADC_HandleTypeDef hadc1;

SPI_HandleTypeDef hspi2;

TIM_HandleTypeDef htim2;
TIM_HandleTypeDef htim4;
TIM_HandleTypeDef htim5;

UART_HandleTypeDef huart1;
UART_HandleTypeDef huart6;

/* USER CODE BEGIN PV */
Motor* motorPtr = nullptr; // Initializing a null pointer to be filled in main after motor instantiation for access by callback.
Encoder* encoderPtr = nullptr;
FSM* FSMptr = nullptr;

volatile uint32_t pressT = 0;  // time for sensing button hold

char msg[50];
int loop = 1;
/* USER CODE END PV */

void SystemClock_Config(void);
static void MX_GPIO_Init(void);
static void MX_SPI2_Init(void);
static void MX_TIM2_Init(void);
static void MX_USART6_UART_Init(void);
static void MX_TIM4_Init(void);
static void MX_TIM5_Init(void);
static void MX_ADC1_Init(void);
static void MX_USART1_UART_Init(void);
/**
  * @brief  The application entry point.
  * @retval int
  */
int main(void)
{

  /* MCU Configuration--------------------------------------------------------*/

  /* Reset of all peripherals, Initializes the Flash interface and the Systick. */
  HAL_Init();

  /* Configure the system clock */
  SystemClock_Config();

  /* Initialize all configured peripherals */
  MX_GPIO_Init();
  MX_SPI2_Init();
  MX_TIM2_Init();
  //MX_USART6_UART_Init();
  MX_TIM4_Init();
  MX_TIM5_Init();
  MX_ADC1_Init();
  //MX_USART1_UART_Init();
  /* USER CODE BEGIN 2 */
  //HAL_TIM_Base_Start(&htim4);	// timer for encoder updating CURRENTLY NOT USING INTERRUPT, CHANGE IF NEEDED to ..._IT
  HAL_TIM_Base_Start(&htim5);	// timer for microsecond timing

  HAL_ADC_Start(&hadc1);		// starting ADC
  Hall my_hall(&hadc1);

  GPIO CSn(GPIOB, GPIO_PIN_12); // Custom GPIO class to interface with pins more easily
  Encoder my_encoder(&hspi2, &htim5, CSn);
  encoderPtr = &my_encoder;


  HAL_TIM_Base_Start_IT(&htim2); // timer for PWM and commutation interrupt
  HAL_TIM_PWM_Start(&htim2, TIM_CHANNEL_3);	//PWMa
  HAL_TIM_PWM_Start(&htim2, TIM_CHANNEL_4); //PWMb
  HAL_TIM_PWM_Start(&htim2, TIM_CHANNEL_1); //PWMc
  GPIO enA(GPIOA, GPIO_PIN_7);
  GPIO enB(GPIOA, GPIO_PIN_4);
  GPIO enC(GPIOA, GPIO_PIN_6);
  Motor my_motor(&htim2, TIM_CHANNEL_3, TIM_CHANNEL_4, TIM_CHANNEL_1, enA, enB, enC, my_encoder);
  motorPtr = &my_motor;


  float kp = 50.0f;	// [rad --> effort] 1.57 --> 80
  float ki = 0.0f;
  float kd = 0.0f;
  PID my_pid(kp, ki, kd, &htim5);

  HAL_Delay(15000); //Delay for Bluetooth pairing

  MX_USART6_UART_Init();
  MX_USART1_UART_Init();

  FSM my_FSM(my_motor, my_encoder, my_pid, my_hall, &huart1);
  FSMptr = &my_FSM;
  /* USER CODE END 2 */

  /* Infinite loop */
  /* USER CODE BEGIN WHILE */
  my_encoder.zero();
  my_motor.enable();
  my_pid.reset();

  while (loop)
  {
	  my_FSM.run((uint32_t)100); // run FSM at 100Hz
    /* USER CODE END WHILE */

    /* USER CODE BEGIN 3 */
  }
  my_motor.disable();
  /* USER CODE END 3 */
}

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
/* USER CODE BEGIN 4 */
void HAL_TIM_PeriodElapsedCallback(TIM_HandleTypeDef *htim) {
    if (htim->Instance == TIM2) {
        motorPtr->commutate();
    }
}

void HAL_GPIO_EXTI_Callback(uint16_t GPIO_Pin) {
    if (GPIO_Pin == GPIO_PIN_1) { // PA1

    	uint32_t now = HAL_GetTick();

    	if (HAL_GPIO_ReadPin(GPIOA, GPIO_PIN_1) == GPIO_PIN_SET) {
            pressT = now;
        }
        else {
            uint32_t pressDur = now - pressT;
            FSMptr->advanceState(pressDur > 1000);
        }
    }
}
/* USER CODE END 4 */
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


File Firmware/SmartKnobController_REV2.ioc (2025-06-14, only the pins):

Mcu.UserName=STM32F411CEUx
PA1.Signal=GPXTI1
PA11.Signal=USART6_TX
PA12.Signal=USART6_RX
PA13.Signal=SYS_JTMS-SWDIO
PA14.Signal=SYS_JTCK-SWCLK
PA2.Signal=S_TIM2_CH3
PA3.Signal=S_TIM2_CH4
PA4.Signal=GPIO_Output
PA5.Signal=S_TIM2_CH1_ETR
PA6.Signal=GPIO_Output
PA7.Signal=GPIO_Output
PB1.Signal=ADCx_IN9
PB10.Signal=GPIO_Output
PB12.Signal=GPIO_Output
PB13.Signal=SPI2_SCK
PB14.Signal=SPI2_MISO
PB15.Signal=SPI2_MOSI
PB2.Signal=GPIO_Output
PB3.Signal=SYS_JTDO-SWO
PB6.Signal=USART1_TX
PB7.Signal=USART1_RX

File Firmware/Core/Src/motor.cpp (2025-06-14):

/*
 * motor.cpp
 *
 *  Created on: Jun 4, 2025
 *      Author: nickl
 *
 */

#include "motor.h"

Motor::Motor(TIM_HandleTypeDef* htim,
             uint32_t chA, uint32_t chB, uint32_t chC,
             GPIO& enA, GPIO& enB, GPIO& enC,
             Encoder& encoder)
    : htim(htim),
      chA(chA), chB(chB), chC(chC),
      enA(enA), enB(enB), enC(enC),
      encoder(encoder), targetEffort(0)
{
}

void Motor::setEffort(int effort) {
    // Store new effort value
	if (effort > 100) {effort = 100;}
	if (effort < -100) {effort = -100;}
	targetEffort = effort;
}

void Motor::commutate() {
	// Commutate target effort to motor, triggered by PWM interrupt in main.cpp

	// Scale effort to desired voltage
	float V_q = (targetEffort * V_max)/100;

	// Read encoder value
	int32_t theta_a = encoder.getCommutationAngle();

	// Phase shift angles in bits
	int32_t theta_b = theta_a - resolution/(polePairs * 3);
	int32_t theta_c = theta_a + resolution/(polePairs * 3);

	// Wraparound correction
	if (theta_b < 0) theta_b += resolution;
	if (theta_c >= resolution) theta_c -= resolution;

	// Convert to 3-phase using lookup table
	float V_a = V_q * commTable[theta_a];
	float V_b = V_q * commTable[theta_b];
	float V_c = V_q * commTable[theta_c];

	//Pass to PWM function
	applyPWM(V_a, V_b, V_c);
}

void Motor::enable() {
    // Sets all motor driver enable pins to high
	enA.high();
	enB.high();
	enC.high();
}

void Motor::disable() {
    // Sets all motor driver enables pins to low
	enA.low();
	enB.low();
	enC.low();
}

void Motor::testCommutation(int32_t theta, float V_q) {
	//Testing commutation without encoder feedback
	int32_t theta_a = theta;
	// Phase shift angles in bits
	int32_t theta_b = theta_a - resolution/(polePairs * 3);
	int32_t theta_c = theta_a + resolution/(polePairs * 3);

	// Wraparound correction
	if (theta_b < 0) theta_b += resolution;
	if (theta_c >= resolution) theta_c -= resolution;

	// Convert to 3-phase using lookup table
	float V_a = V_q * commTable[theta_a];
	float V_b = V_q * commTable[theta_b];
	float V_c = V_q * commTable[theta_c];

	//Pass to PWM function
	applyPWM(V_a, V_b, V_c);
}

void Motor::applyPWM(float Va, float Vb, float Vc) {
    // Apply motor voltages to PWM signals
	uint32_t AR = __HAL_TIM_GET_AUTORELOAD(htim);

	// Normalizing to [0 , 1]
	float dutyA = (Va / (2.0f * V_max)) + 0.5f;
	float dutyB = (Vb / (2.0f * V_max)) + 0.5f;
	float dutyC = (Vc / (2.0f * V_max)) + 0.5f;

	__HAL_TIM_SET_COMPARE(htim, chA, dutyA * AR);
	__HAL_TIM_SET_COMPARE(htim, chB, dutyB * AR);
	__HAL_TIM_SET_COMPARE(htim, chC, dutyC * AR);
}

// Commutation constants table for transforming voltage set point to 3-phase signals without floating point trig
// Must be manually switched if encoder resolution or pole count is switched.
// Calculated with the following math:
// X = -2/3 * sin(22 * π * (enc_angle / 16384))
const float Motor::commTable[16384] = {
		-0.000000f,
		-0.002812f,
		-0.005625f,
		-0.008437f,
		-0.011249f,
		-0.014060f,
		-0.016872f,
		-0.019683f,
		-0.022494f,
		-0.025305f,
		-0.028115f,
		-0.030924f,
		-0.033733f,
		-0.036542f,
		-0.039349f,
		-0.042156f,
		-0.044963f,
		-0.047768f,
		-0.050573f,
		-0.053376f,
		-0.056179f,
		-0.058981f,
		-0.061782f,
		-0.064581f,
		-0.067380f,
		-0.070177f,
		-0.072973f,
		-0.075768f,
		-0.078561f,
		-0.081353f,
		-0.084144f,
		-0.086933f,
		-0.089720f,
		-0.092506f,
		-0.095291f,
		-0.098073f,
		-0.100854f,
		-0.103633f,
		-0.106410f,
		-0.109186f,
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
};

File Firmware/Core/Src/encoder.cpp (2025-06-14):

/*
 * encoder.cpp
 *
 *  Created on: Jun 4, 2025
 *      Author: nickl
 *
 */

#include "encoder.h"

Encoder::Encoder(SPI_HandleTypeDef* hspi, TIM_HandleTypeDef* htim, GPIO& CSn)
    :
	rawAngle(0),
	hspi(hspi),
	htim(htim),
	CSn(CSn),
	zeroAngle(0),
	resetAngle(0),
	prevT(0),
	prevAngle(0),
	rawPosition(0),
	rawVelocity(0),
	dPos(0),
	dt(0)
{
}

void Encoder::update() {
    // Update raw angle data
	rawAngle = readRawAngle(); // [bits]

	// Update raw position data
	dPos = rawAngle - prevAngle;
	// "Over/underflow" protection
	if(dPos > (resolution)/2){
		dPos -= (resolution);
	}
	else if(dPos < -(resolution)/2){
		dPos += (resolution);
	}
	rawPosition += dPos; // [bits]

	// Update raw velocity data
	// Not implementing overflow protection on timer, should be short enough usage.
	uint32_t t = micros();
	dt = t - prevT;

	rawVelocity = (dPos*1000)/((int32_t)dt); // [bits/ms] - keeping everything as integers.

	// Update previous values
	prevAngle = rawAngle;
	prevT = t;
}

int32_t Encoder::getCommutationAngle() {
	// Access the angle relative to electrical zero reference in integer bits
	int32_t commRawAngle = readRawAngle();
	int32_t angle = (int32_t)commRawAngle - commutationZeroAngle; // cast values to prevent wrap-around instead of negative results.
	if (angle < 0) {
		angle += resolution;
	}
	return angle;
}

float Encoder::getAngle() {
    // Convert rawAngle to [rad]
	int32_t angle = (int32_t)rawAngle - (int32_t)zeroAngle; // cast values to prevent wrap-around instead of negative results.
	if (angle < 0) {
		angle += resolution;
	}
	return (2 * (float)M_PI * (float)angle) / (float)resolution;
}

float Encoder::getPosition() {
	// Convert rawPosition to [rad]
	int32_t position = rawPosition - ((int32_t)zeroAngle - (int32_t)resetAngle); // cast values to prevent wrap-around instead of negative results.
	return (2 * (float)M_PI * (float)position) / (float)resolution;
}

float Encoder::getVelocity() {
    //Convert rawVelocity to [rad/s]
    return (2000 * (float)M_PI * (float)rawVelocity) / (float)resolution;
}

void Encoder::zero() {
    // Sets 0deg datum, must reset rawPosition to avoid inconsistency
	update();
	zeroAngle = rawAngle;
	// do resetPosition stuff without updating the encoder again.
	rawPosition = 0;
	resetAngle = rawAngle;
}

void Encoder::resetPosition() {
    // Resets the accumulating position measurement,
	// records the rawAngle where position was reset so it can be offset from zero and reference aligns with rawAngle.
	update();
	rawPosition = 0;
	resetAngle = rawAngle;
}

uint16_t Encoder::readRawAngle() {
	//Return raw SPI bit value of encoder

	__disable_irq();

	uint16_t encPosAddr = 0x3FFF;
	uint16_t encPosBuf;

	//Go go SPI!
	CSn.low(); // logic-low on CSn pin, custom functions
	HAL_SPI_TransmitReceive(hspi, (uint8_t*)&encPosAddr, (uint8_t*)&encPosBuf, 1, HAL_MAX_DELAY);
	CSn.high(); // logic-high on CSn pin, custom functions

	__enable_irq();

	//return encPosBuf & 0x3FFF;
    return (16384 - (encPosBuf & 0x3FFF)) % 16384;
    // masking first two bits to get 14-bit position data as integer
    // reversing the direction that angle accumulates as encoder rotates to align CCW+
}

uint32_t Encoder::micros() const {
    //Return time in microseconds
	return __HAL_TIM_GET_COUNTER(htim);
}

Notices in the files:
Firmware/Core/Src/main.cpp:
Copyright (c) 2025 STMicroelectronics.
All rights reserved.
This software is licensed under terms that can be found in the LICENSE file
